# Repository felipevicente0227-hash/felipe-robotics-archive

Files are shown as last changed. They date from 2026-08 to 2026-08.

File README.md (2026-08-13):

# Felipe Robotics Archive

Robotics and embedded-systems projects, 2020–2026: international competition robots, a self-built experimental physics apparatus, and embedded control systems. Built across Taiwan, Japan, Korea, Australia, and Spain.

**About this archive.** I build physical systems and debug them until they work: sensor-driven robots, microcontroller timing systems, and electromechanical builds. My recent work centers on measurement and systematic-error analysis (Arduino photogate investigation, 2026) and embedded integration (ESP32 hovercraft, UPM Madrid, 2026). Earlier competition projects (2020–2023) document the progression from guided sensor/DC-motor builds to independently designed and coded robots.

## Engineering Progression

| Year | Project | Main engineering area | Evidence in repo |
|---|---|---|---|
| 2026 | Arduino Photogate — g measurement | Experimental design, systematic error analysis, embedded timing | Raw data (45 trials), source code, results summary, follow-up analysis, video |
| 2026 | ESP32 Hovercraft (UPM Madrid) | Embedded networking, ESC/servo integration, assembly | Code, CAD, videos, camp reference repo |
| 2023–24 | Humanoid Hand (incomplete) | Servo control, guided ML build | Photos, video |
| 2023 | Flame Guardian | Camera-based detection, IoT alerting | Detection model, alert code, demo video (YouTube) |
| 2023 | URC Australia — Mechanical Crank (1st place) | Mechanical design, threshold tuning | Design files, photos |
| 2021 | Korea RoboSTEAM — Patient Transfer (1st place) | Line-tracing algorithms, route strategy | Design files, videos, photos |
| 2020 | Japan — Light Adventurer (1st place) | Sensor zoning concept, DC motor control | Photos, video |

---

##  Flagship: [Arduino Photogate — Measuring g and Diagnosing Systematic Timing Error (2026)](photogate-free-fall/)

**Fully solo project** (IB Physics Internal Assessment): designed, built, coded, and analyzed over ~3 months of near-daily lab sessions.

A servo-release + LDR photogate free-fall rig, timed by an Arduino at microsecond resolution. Rather than a single measurement, the investigation used release height (20–100 cm, 9 heights × 5 trials) as a **diagnostic variable** to expose a systematic timing error.

**Key results:**
- Naive model (x = ½gt²): g = 8.46 m/s² — 13.8% below accepted value despite r² = 0.999
- Corrected model (t = √(2x/g) + Δt, from inspecting my own control code): **g = 9.14 ± 0.16 m/s², r² = 0.9995** (6.8% difference)
- The systematic delay was traced to a specific design decision: one button press both starts the µs timer and commands the servo release, so every trial includes the servo's rotation time
- Delay quantified two independent ways: **28 ms** (regression intercept) vs **40 ± 3.6 ms** (comparison against SUVAT-predicted times) — consistent order of magnitude from different assumptions

**What I would change:** log the servo's actual release moment via a limit switch to separate mechanical delay from LDR detection lag; replace the shared start signal with a break-beam at the release point, removing the offset at its source.

 Raw data, source code, results summary, and follow-up analysis in the [`photogate-free-fall`](photogate-free-fall/) folder. (Full report to be added after IB submission.)

---

##  [ESP32 Hovercraft — UPM Madrid Summer Camp (2026)](esp32-hovercraft-upm/)

Phone-controlled hovercraft: the ESP32 broadcasts its own Wi-Fi access point and serves a control page — thrust slider drives a brushless motor through an ESC (0–180 mapped to 1000–2000 µs pulses); steering drives a rudder servo (software-limited 45°–135°).

**My role & attribution:** Built at ETSII UPM's summer camp under instructor guidance ([camp reference repo](https://github.com/JaimeBravoAlgaba/campamento_verano_ETSII_2026)). The Wi-Fi/web framework was instructor-provided as a starter template; I completed the ESC and servo integration (pin config, pulse-width setup, control loop), and led the physical design, assembly, ESC calibration, and flight tuning within my team. Our team's own CAD variants remained on camp laptops; the archived CAD files are the camp reference designs.

---

##  [Flame Guardian (2023)](2023-flame%20guardian/)

Wildfire detection and alert system: camera-based fire detection triggering automatic email alerts with location data, designed for remote assessment and response via a web interface.

**My role:** Team of four. I led research, wrote the code, built and assembled the hardware, and integrated and tested the fire-detection model. Kristy built the demonstration diorama; a third teammate wrote the research report.

**What survives in this repo vs. the original system:** the light-sensor email-alert module (`FireDefenderMailSending.py`), the detection model (`fire_detection.xml`), and a supporting script. The integrated competition system (camera pipeline + GPS tagging + web control) is documented in the [demo video](https://www.youtube.com/watch?v=Y2XW8qYtMfY) but its full code is not archived.

**Known limitations I'd fix today:** the sensor module detects brightness *change* (1 Hz sampling), not fire directly; SMTP sending blocks execution; no Wi-Fi retry logic; detection accuracy was never formally measured.

---

##  Competition Robots (2020–2023)

### [Korea RoboSTEAM 2021 — Autonomous Patient Transfer Robot (1st place)](2021%20Korea%20Champion%20-%20Autonomous%20Patient%20Transfer%20Robot/)
Line-following robot that locates colored blocks (representing patients) and delivers each to its matching zone.
**My role:** Largely solo — pandemic restrictions meant near-daily individual lab sessions. I built the robot and wrote the tracing code, including escape functions for recovery and route strategy optimized for time-based scoring. The hardest part was tuning: the robot doesn't learn, so behavior was refined through repeated simulated runs and threshold iteration.

### [URC Australia, September 2023 — Mechanical Crank System (1st place)](2023%20Australia%20Champion%20-%20Mechanical%20Crank%20System/)
Rebuild campaign after losing at Osaka 2023 earlier that summer.
**My role:** I designed and built the new robot, wrote roughly half the code, and did all threshold tuning and testing; my teammate wrote the remaining functions.

### [Japan 2020 — Light Adventurer (1st place)](2020%20Japan%20Champion%20-%20Automatic%20Plant%20Watering%20Robot/)
A robot that moves a plant toward optimal light, then waters it automatically.
**My role:** I proposed the concept and the core sensing idea — splitting a servo's 180° sweep into three 60° zones and comparing light readings to pick a direction. My teacher taught me the implementation, building the code with me line-by-line; I did most of the physical build. Included here as the starting point of the progression, not as evidence of current ability.

---

##  [Humanoid Hand (2023–2024, incomplete)](humanoid-hand/)

Guided self-taught build of a sensor-mimicking humanoid hand from an online tutorial. Left incomplete when I moved to Spain — archived honestly as such.

## License
MIT — see [LICENSE](LICENSE).

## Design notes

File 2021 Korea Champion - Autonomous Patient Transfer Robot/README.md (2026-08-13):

# 2021 Korea Champion — Autonomous Patient Transfer Robot

Line-tracing autonomous robot that locates colored blocks (representing patients) and delivers each to its matching colored zone on a marked course. Built for the Korea RoboSTEAM competition, 2021.

## Files

- `korea - automatic Patient Transfer Robot/` — six block-editor programs (`.bpd`). These are binary files from a block-based programming environment and cannot be read as text; the specific editor they belong can be downlanded from 'https://www.artec-kk.co.jp/studuino/en/studuino.php'
  
  - `Felipe_Korea.bpd`, `Korea RoboSTEAM.bpd` — main programs
  - `FCB_UPside 0207.bpd` / `FCB_UPside 0220a.bpd`, `FCB_down0207.bpd` / `FCB_down0220A.bpd` — upper and lower mechanism programs, in dated revisions (7 Feb and 20 Feb)
- `korea championship robot map line tracing.mp4` — line tracing over the course map
- `korea championship robot trial 2.mp4` — competition trial run
- 8 build photographs (January 2021)

## Tested conditions & limitations

**Hardware disassembled — the behaviour described here is documented from the competition videos and build photographs in this folder, not from a live re-test.** The programs are stored in a binary block-editor format, and can be opened through the studuino bit prodram

The controller platform and sensor kit, the line colour and surface, and the number of line sensors were not saved, and cannot be recovered from the binary program files. Known failure modes were not written down at the time. Course length, run times, success rate and payload mass were not recorded either, and the hardware no longer exists to re-measure them.

The two dated revisions of each mechanism program (0207 → 0220) show the logic was retuned between those dates; what specifically changed is not recorded.

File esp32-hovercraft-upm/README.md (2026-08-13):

# ESP32 Hovercraft

A wi-fi controlled hovercraft built around an ESP32. The board broadcasts its own wi-fi access point and serves a control webpage — any phone that joins the network gets two sliders: one for thrust, one for steering. No app, no RC receiver, no pairing. The hovercraft is the network.

Origin & attribution: Built at ETSII UPM's summer camp under instructor guidance (camp reference repo). The Wi-Fi/web framework came as an instructor starter template; I completed the ESC and servo integration and led my team's physical design, assembly, calibration, and flight tuning. Our team's own CAD variants stayed on camp laptops — the .f3d files archived here are the camp's reference designs.

Built July 2026. Videos: hoverboard1.mp4, hoverboard2.mp4.

## How it works

The ESP32 runs in access-point mode (WiFi.softAP) and hosts a web server on port 80.

The served page has two sliders. Moving a slider sends `GET /set?device=esc&val=N` (or `device=servo`) to the board.

- Thrust: the value (0–180) drives a brushless motor through an ESC attached with 1000–2000 µs pulse widths.
- Steering: the value turns a rudder servo, constrained in software to 45°–135° so it can never slam past its physical limits.
- Failsafe: the web page sends a heartbeat ping every 300 ms. If the board hears nothing for 1 second (phone left the network, browser closed), the throttle is cut to zero automatically. Without this, a dropped connection would hold the motor at its last value forever.

## Hardware

| Part | Role |
|---|---|
| ESP32 dev board | Wi-fi access point + web server + control |
| Brushless motor + ESC | Thrust (ESC signal on GPIO 32) |
| Rudder servo | Steering (signal on GPIO 33) |
| LiPo battery | Power for ESC/motor; ESP32 powered per your setup |

## 3D-printed parts (Fusion 360)

All parts designed in Fusion 360 and 3D printed (.f3d source files in this repo):

- redirigir_aire.f3d — air-redirect duct
- soporterbrushless.f3d — brushless motor mount
- tubo.f3d — thrust tube
- timonV2.f3d — rudder (the camp's second-revision reference design)

## Setup

1. Open ESP_hovercraft.ino in the Arduino IDE with the ESP32 board package and the ESP32Servo library installed.
2. Set WIFI_SSID and WIFI_PASSWORD to whatever you want the hovercraft's network to be called.
3. Flash the board. Open the serial monitor at 115200 baud to see the access point IP (default 192.168.4.1).
4. On your phone, join the hovercraft's wi-fi network, open a browser, and go to the IP address. Slide to fly.

## Safety notes

- The throttle slider starts at 0 and the ESC arms at 0 on boot — but always treat a powered brushless motor as live. Keep fingers and loose clothing away from the fan.
- The failsafe cuts thrust on disconnect, but it does not brake the hovercraft; it will coast.
- Test with the propeller removed first when changing the code.

## Tested conditions & limitations

Everything in the **verifiable** list is read directly from `ESP_hovercraft.ino`. The second list is what has not been measured yet.

**Verifiable from the code:**

- Failsafe: the throttle is cut to zero after **1 second** without a heartbeat (`FAILSAFE_TIMEOUT_MS 1000`), with the page pinging every 300 ms — so up to three pings can be lost before it trips.
- After the failsafe fires it clears the link flag, so thrust stays at zero until the page reconnects and the slider is moved again. It does not resume on its own.
- The failsafe cuts thrust only. The rudder holds its last angle, and the hovercraft coasts rather than braking.
- Steering is constrained in software to **45°–135°**, so a malformed or out-of-range request cannot drive the rudder past its physical limits. Thrust is constrained to 0–180.
- The access point is open to anyone who joins the network and knows the IP: there is no authentication on `/set`, and traffic is plain HTTP. Anyone on the wi-fi can take control.
- **Not yet tested with two phones connected at once.** Nothing in the code arbitrates between clients, so the last request received wins and either phone's heartbeat keeps the failsafe from tripping for both.
- Control range is bounded by the ESP32's own access point, since the board makes the network rather than joining one.

**Not yet measured — the hardware remained at the UPM camp in Madrid and is no longer accessible, so these would require a rebuild:**

- Control range from the board — not yet measured
- Run time on a full battery, and the battery specification — not yet measured
- Total mass as flown — not yet measured
- Thrust value at which it lifts off the surface — not yet measured
- Failsafe behaviour in a real walk-away test, as opposed to on the bench — not yet recorded

Endurance beyond short demonstration runs was never characterised, and the two-client case noted above was never tested; with the hardware left behind at the camp, closing either gap would mean rebuilding the unit.

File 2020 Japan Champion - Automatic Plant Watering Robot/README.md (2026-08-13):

# 2020 Japan Champion — Automatic Plant Watering Robot

Championship-winning robot that tracks a light source and waters a plant automatically. Built for a robotics competition in Japan, 2020.

This folder holds build photographs (August–December 2020) and a video demo. No source code was archived for this project.

## Files

- `automatic plant watering robot video demo.mp4` — the robot running end to end
- 10 build photographs documenting the mechanism and assembly

## Tested conditions & limitations

**Hardware disassembled — the behaviour described here is documented from the competition video and build photographs in this folder, not from a live re-test.** No source code was archived either.

Verifiable from the video: a servo-mounted light sensor sweeps 0°–180°, sampling three zones — left, front, and right — stored in the block code as variables `LA`, `FA`, and `RA`. The robot compares the three readings and drives toward whichever zone is brightest, then waters the plant automatically on arrival; watering duration is adjustable in the code. Two demonstration runs are shown, one with the light source to the right and one in front, and the robot reaches the correct zone both times.

Not recoverable: the controller platform, the specific light source used in testing, the watering mechanism's hardware, and the competition category it was entered under were never saved. No quantitative figures exist either — tracking range, response time, water volume per cycle, and reservoir run time were never measured, and the hardware no longer exists to measure them now.

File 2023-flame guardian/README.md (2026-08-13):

# Flame Guardian (2023)

Fire detection system in two independent halves:

- **`fireDetect`** — runs on a laptop, watches a webcam with an OpenCV Haar cascade, draws a box around detected flame and sounds an alarm.
- **`FireDefenderMailSending.py`** — runs standalone on a Studuino:bit board, watches the on-board light sensor and sends a Gmail alert when the light level jumps.

The full competition build also included GPS location tagging, on-site image capture, and automatic extinguishing triggered through a web-based servo control interface — all demonstrated working at the time (see the servo-control webpage in the project demo). That code was never archived and no longer exists; only the two scripts above survive in this repo, and they don't communicate with each other (see Tested conditions & limitations below).

`fire_detection.xml` is the pre-trained Haar cascade used by the camera half.

## Running it

The camera half needs `opencv-python` and `pygame`, and must be run from inside this folder (it loads `fire_detection.xml` by relative path). The board half reads its wi-fi and Gmail credentials from environment variables — `WIFI_SSID`, `WIFI_PWD`, `GMAIL_ADDR`, `GMAIL_PWD`, `SEND_MAIL_ADDR` — so that no credentials live in this repo. `GMAIL_PWD` must be a Gmail App Password; with 2FA enabled Google rejects a plain account password over SMTP.

## Tested conditions & limitations

Everything in the **verifiable** list is read directly from the source in this folder. Everything after it is a real-world result that was never recorded.

**Verifiable from the code:**

- The two surviving halves never communicate. The camera half sounds an alarm but sends no email; the board half sends email but sees no camera. There is no combined mode in the code that remains in this repo.
- The board half triggers on the *change* in light level between one-second samples, not the absolute level — a jump greater than `threshold = 500` raw units. Consequences: a fire already burning when the script starts is never reported, and a fire that brightens gradually over more than a second may never produce a large enough single-sample jump.
- Sampling is 1 Hz, and `sendmail` blocks for the duration of the SMTP exchange, so detections during a send are missed.
- If wi-fi fails to connect the board shows `W` and exits — it does not retry.
- The camera half loads `audio.wav` (the alarm sound, committed alongside the script) by relative path, so it must be run from inside this folder or it will fail at startup.
- On each detection the camera half plays the alarm and sleeps 1 second, blocking the capture loop, so frames are dropped for as long as flame stays in view.
- The camera half never calls `cap.release()` or `cv2.destroyAllWindows()`; the webcam is freed only when the process exits.
- Haar cascade parameters are `scaleFactor 1.2`, `minNeighbors 5` — the false-alarm trade-off dial. It uses the default webcam (index 0).

**Not recorded anywhere in this repo:**

Detection distance, flame size and type, and the lighting conditions used in testing were not recorded at the time. Detection rate, miss rate and false-positive rate were never formally measured — the system was demonstrated rather than characterised, so there is no trial count to quote. Whether an alert email was confirmed to arrive end to end is not recorded either. The board is a Studuino:bit, identified from the `pystubit` imports; its firmware version was not noted. The GPS tagging, image capture, and servo-based extinguishing control shown in the competition demo video are not represented by any surviving code in this repo.

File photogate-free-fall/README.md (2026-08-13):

# Arduino Photogate: Measuring g and Diagnosing Systematic Timing Error

**Solo project** — designed, built, coded, and analyzed independently (IB Physics Internal Assessment, 2026). ~3 months of near-daily lab sessions.

## The question
Not just "measure g" — the investigation used release height as a **diagnostic variable**: if a fixed timing delay exists in the apparatus, it should distort short falls more than long ones. Varying height turns a nuisance error into something measurable.

## The apparatus
- Servo-controlled release arm at the top of a vertical stand
- Single LDR photogate above a catcher, read on Arduino analog pin A0 (threshold: 320/1023)
- One button press releases the sphere AND starts a microsecond timer (`micros()`)
- 200 ms ignore window after release, because the servo's own motion was found to disturb the light reading during preliminary testing
- Same metal sphere for all trials; heights 20–100 cm in 10 cm steps, 5 trials each (45 measurements)

## Key results
| Model | g (m/s²) | vs 9.81 | r² |
|---|---|---|---|
| Naive x = ½gt² | 8.46 | −13.8% | 0.9992 |
| Corrected t = √(2x/g) + Δt | **9.14 ± 0.16** | −6.8% | 0.9995 |

The corrected model came from **reading my own control code**: the timer starts at the button press, but the sphere only falls once the servo finishes rotating — so a fixed delay is added to *t*, not *t²*.

The delay was quantified two independent ways:
- **28 ms** — intercept of the t vs √x regression (no assumption about g)
- **40 ± 3.6 ms** — mean gap between measured times and SUVAT predictions (assumes g = 9.81)

Same order of magnitude from different assumptions → real, fixed offset.

## What went wrong along the way
- The servo's motion falsely triggered the LDR immediately after release → added the 200 ms ignore window
- Early trials showed derived g *rising* with height (7.16 → 8.23 m/s²) under the naive model — initially confusing, eventually the key clue that the error was a fixed additive delay

## Follow-up analysis
See [FOLLOWUP.md](FOLLOWUP.md): applying the correction flattens the per-height g values completely (σ = 0.09 m/s²), confirming the diagnosis — and reveals a residual ~6.8% systematic error the additive-delay model does not explain.

## What I would change (V2)
- Break-beam at the release point so timing starts when the fall actually starts — removing the offset at its source
- Log the servo's completion moment (limit switch / feedback pin) to separate mechanical delay from LDR lag
- More trials at 20–40 cm, where the offset is proportionally largest and most diagnostic

## Tested conditions & limitations

**Uncertainty:** timer resolution is negligible against the trial-to-trial spread. The dominant error was not random but systematic: the 28 ms to 40 ± 3.6 ms servo release delay described above.

**Verifiable from the code:**

- Timing uses `micros()` and is printed to 6 decimal places — chosen because a sub-second drop needs far finer resolution than `millis()` gives.
- `threshold = 320` is a raw `analogRead` value, calibrated against one specific lamp and room. It is not adaptive: move the rig to different ambient lighting and this must be re-tuned or the gate will either trip immediately or never trip.
- A 200 ms blanking window (`ignoreUntil`) after release ignores the photoresistor, because the servo arm sweeps through the sensor's view on its way out. Any drop that completes in under 200 ms therefore cannot be measured.
- The comparison `currentTime > ignoreUntil` is a direct unsigned comparison rather than a rollover-safe subtraction. `micros()` wraps roughly every 71 minutes of board uptime, so a run started near the wrap point can blank incorrectly. Power-cycling between sessions avoids this.
- Only one gate is present, so the device measures total time from release to the gate. It cannot measure instantaneous velocity or acceleration directly — those come from the drop height, which the sketch never knows.
- The sketch prints a serial line on every loop iteration while timing. At 115200 baud these writes block once the buffer fills, so the photoresistor sampling interval is bounded by serial throughput, not by the loop itself. This adds jitter to when the shadow is actually noticed.
- After a run auto-stops, the servo gate position and the timer state are tracked by two separate flags that are only toggled together on a button press — so the gate can end up in the opposite position from the one the next run expects. See "Known issue" below.

**Known issue (documented, not fixed):** `detecting` is cleared automatically when the ball is detected, but `at90` is not. The next button press therefore moves the servo to 50° instead of 90° while starting a new timing run, so the gate needs an extra press to resynchronise.

**Not measured:** the residual ~6.8% gap between the corrected g and 9.81 m/s² is unexplained by the additive-delay model. Separating LDR detection lag from height-measurement bias needs the V2 hardware changes above; neither was measured here.

## Files
- `final_project_code.ino` — release + timing code
- `raw_data.csv` — all 45 trial times
- `felipe 2026 physics ia free fall experiment using arduino.mp4` — video of the experiment running
- `FOLLOWUP.md` + `photogate_correction_followup.png` — post-IA correction analysis
- `generate_figure.py` — reproduces the figure from the data
- Full IA report: added after IB submission (academic integrity)

## TODO
- [ ] Apparatus photo at top
- [ ] t vs √x regression graph

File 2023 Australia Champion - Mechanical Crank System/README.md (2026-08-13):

# 2023 Australia Champion — Mechanical Crank System

Mechanical crank system built for the URC competition, Australia, 2023.

The competition took place in September 2023. The later materials in this folder — program revisions dated November 2023, December photographs, and the URC-AUS-2024 revision — are post-competition development toward the following URC season.

## Files

- `2023- australia/` — four block-editor programs (`.bpd`). These are binary files from a block-based programming environment and cannot be read as text; the specific editor they belong can be downloaded from'https://www.artec-kk.co.jp/studuino/en/studuino.php'
  
  - `URC20231113.bpd`, `URC20231126.bpd`, `URC-AUS-2024.bpd` — post-competition revisions, all dated after the September 2023 event (13 Nov 2023, 26 Nov 2023, and a later 2024 revision); none of them is the version run at the competition
  - `備品機_URC澳洲.bpd` — a separate variant; what distinguishes it from the others was not recorded
- 5 build photographs (September and December 2023)

## Tested conditions & limitations

**Hardware disassembled — the behaviour described here is documented from the build photographs in this folder, not from a live re-test.** There is no video demo for this project,the programs are stored in a binary block-editor format, and can be opened using the studuino bit program listed above 

The controller platform and actuators, the mechanical function of the crank itself, the competition task it performed and its result, and its known failure modes were not recorded, and cannot be recovered from the binary program files or the photographs. Load, torque, range of travel and cycle time were never measured; the system was built to complete a competition task rather than to a specification, and the hardware no longer exists to measure them now.

The three dated revisions (13 Nov 2023 → 26 Nov 2023 → 2024) show the design was iterated after the September 2023 competition; what specifically changed between them is not recorded.

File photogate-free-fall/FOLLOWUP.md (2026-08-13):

## Follow-up analysis: applying the timing correction

The original investigation's Improvements section proposed applying the identified timing correction directly and re-running the analysis. Done here, using the same raw data (no new hardware required).

**Method:** subtract each delay estimate from every measured average time (t_corrected = t − Δt), then recompute per-height g = 2x/t² and re-fit the naive t² vs x model.

**Results:**

| Correction applied | Regression g (m/s²) | vs 9.81 | Per-height g spread |
|---|---|---|---|
| None (original) | 8.46 | −13.8% | 7.16 → 8.23 (rises with height) |
| Δt = 28 ms (regression intercept) | 9.14 | −6.8% | 9.03 → 9.31 (flat, σ = 0.09) |
| Δt = 40.3 ms (SUVAT offset) | 9.48 | −3.4% | mean 9.86 ± 0.24 |

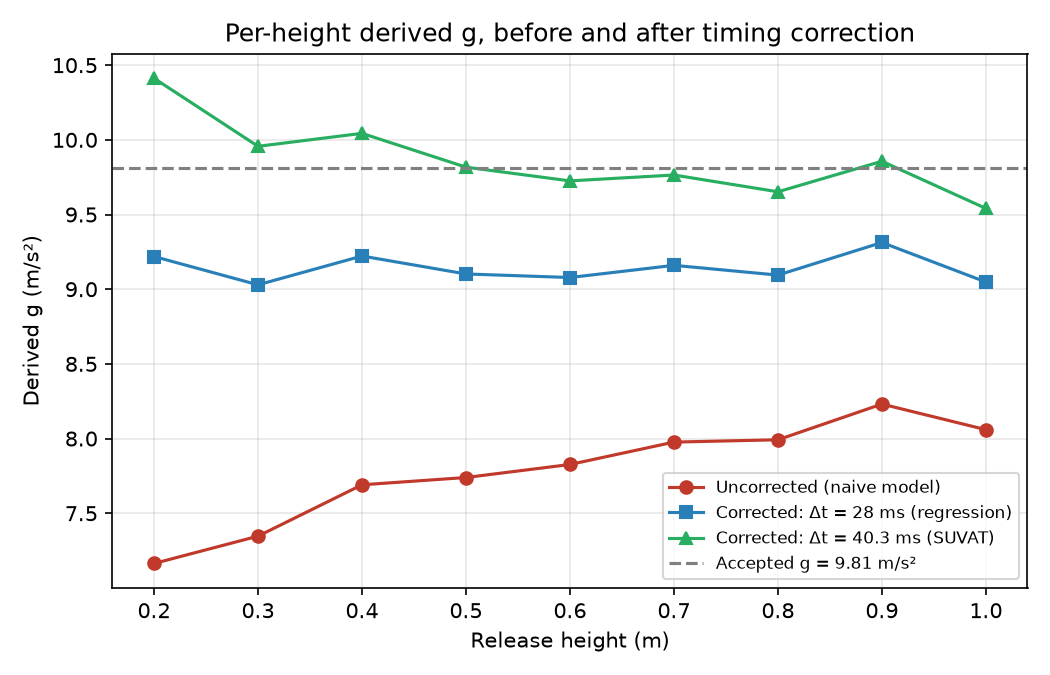
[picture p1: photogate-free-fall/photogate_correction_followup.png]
Per-height g before and after correction


**What this shows:**

1. **The diagnosis is confirmed.** Uncorrected, derived g climbs systematically with height (7.16 → 8.23) — the fingerprint of a fixed additive delay. After the 28 ms correction, that trend vanishes: g is flat across all nine heights (σ = 0.09 m/s²). The height-dependence was entirely an artifact of the timing offset, as predicted.

2. **One honest caveat:** re-fitting after subtracting the regression's own intercept necessarily returns the same g (9.14) — that step is a self-consistency check, not new information. The genuinely new result is the flattening of the per-height values.

3. **A residual systematic error remains.** Even fully corrected by the data-derived delay, g = 9.14 sits 6.8% below 9.81 — larger than the statistical uncertainty (±0.16). The additive-delay model explains the height-dependence but not the entire gap. Remaining candidates: LDR detection lag that grows with impact speed, a small systematic height measurement bias, or the sphere receiving a slight push at release. Distinguishing these requires the hardware changes proposed in Improvements (release-point break-beam, servo feedback logging).

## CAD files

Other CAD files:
esp32-hovercraft-upm/redirigir aire.f3d
esp32-hovercraft-upm/soporterbrushless.f3d
esp32-hovercraft-upm/timonV2.f3d
esp32-hovercraft-upm/tubo.f3d

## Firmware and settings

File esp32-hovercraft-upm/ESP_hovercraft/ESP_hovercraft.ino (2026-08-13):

#include <ESP32Servo.h>
#include <WiFi.h>
#include <WebServer.h>

// ESP32 Wi-Fi network name and password
#define WIFI_SSID "any user name"
#define WIFI_PASSWORD "any password"

// Brushless ESC and servo pins
#define PIN_ESC 32
#define PIN_SERV 33

// Failsafe: if no message arrives from the phone for this long,
// the throttle is cut to zero. The web page sends a heartbeat every
// 300 ms, so this only triggers on a real disconnect.
#define FAILSAFE_TIMEOUT_MS 1000

Servo esc;
Servo servo;
WebServer server(80);

// ---------- ESC ----------
// ESC value received from the web interface (0 = motor off)
int escweb = 0;

// ---------- SERVO ----------
// Servo value received from the web interface (90 = rudder centered)
int servoweb = 90;

// ---------- FAILSAFE ----------
unsigned long lastContactMs = 0; // last time we heard from the client
bool linkActive = false; // true once a client has connected

// Web page (HTML)
const char index_html[] PROGMEM = R"rawliteral(
<!DOCTYPE html>
<html>
<head>
<meta name="viewport" content="width=device-width, initial-scale=1">
<title>Brushless and Servo Control</title>
<style>
body {
font-family: Arial;
text-align: center;
margin: 0;
padding: 20px;
}
h2 { margin-bottom: 20px; }
.value { font-weight: bold; font-size: 1.3em; }

.control-block {
margin: 25px auto;
max-width: 500px;
}
.slider {
width: 90%;
height: 40px;
}
</style>
<script>
function updateESC(value) {
document.getElementById("escweb").innerText = value;
fetch("/set?device=esc&val=" + value);
}
function updateServo(value) {
document.getElementById("servoweb").innerText = value;
fetch("/set?device=servo&val=" + value);
}
// Heartbeat: tell the hovercraft we are still connected.
// If these stop arriving (phone left the network, browser
// closed), the failsafe cuts the motor within one second.
setInterval(function () {
fetch("/ping").catch(function () {});
}, 300);
</script>
</head>
<body>
<h2>Brushless and Servo Control</h2>

<div class="control-block">
<h3>Brushless Motor</h3>
<input type="range" min="0" max="180" value="0" class="slider"
oninput="updateESC(this.value)">
<div>Value: <span id="escweb" class="value">0</span></div>
</div>

<div class="control-block">
<h3>Servo</h3>
<input type="range" min="45" max="135" value="90" class="slider"
oninput="updateServo(this.value)">
<div>Value: <span id="servoweb" class="value">90</span></div>
</div>

</body>
</html>
)rawliteral";

void markContact() {
lastContactMs = millis();
linkActive = true;
}

void handleRoot() {
markContact();
server.send(200, "text/html", index_html);
}

void handlePing() {
// Heartbeat from the web page; refreshes the failsafe timer.
markContact();
server.send(200, "text/plain", "OK");
}

void handleNotFound() {
server.send(404, "text/plain", "Not found");
}

void handleSet() {
String device = server.arg("device"); // "servo" or "esc"
String valStr = server.arg("val");

markContact();

if (valStr.length() == 0) {
server.send(400, "text/plain", "Missing 'val' parameter");
return;
}

int newValue = valStr.toInt();

if (device == "esc") {
// Store the ESC value
escweb = constrain(newValue, 0, 180);
server.send(200, "text/plain", "OK");
}
else if (device == "servo") {
// Store the servo value
servoweb = constrain(newValue, 45, 135);
server.send(200, "text/plain", "OK");
}
else {
server.send(400, "text/plain", "Invalid device. Use 'esc' or 'servo'");
}
}

void setup() {
Serial.begin(115200);

// Attach ESC (minimum and maximum pulse widths in microseconds)
esc.attach(PIN_ESC, 1000, 2000);
servo.attach(PIN_SERV);

// Initialize ESC and servo positions (motor off, rudder centered)
esc.write(escweb);
servo.write(servoweb);

// -------- Wi-Fi Access Point Setup --------
WiFi.mode(WIFI_AP);
WiFi.softAP(WIFI_SSID, WIFI_PASSWORD); // Create its own Wi-Fi network

IPAddress apIP = WiFi.softAPIP(); // Assign the access point IP address
Serial.print("Access point IP: ");
Serial.println(apIP);

// Serve the web page when a client requests the root URL
server.on("/", handleRoot);

// Receive slider values and store them
server.on("/set", handleSet);

// Heartbeat endpoint for the failsafe
server.on("/ping", handlePing);

server.onNotFound(handleNotFound);

server.begin();
Serial.println("Web server started");
}

void loop() {
// Check for incoming HTTP client requests
server.handleClient();

// -------- Failsafe --------
// If the phone disconnects mid-flight, the last throttle value
// would otherwise be held forever. Cut the motor to zero if we
// haven't heard from the client within the timeout.
if (linkActive && (millis() - lastContactMs > FAILSAFE_TIMEOUT_MS)) {
escweb = 0;
linkActive = false;
Serial.println("Failsafe: connection lost, throttle cut to 0");
}

// Send the latest values to the ESC and servo
esc.write(escweb);
servo.write(servoweb);
}

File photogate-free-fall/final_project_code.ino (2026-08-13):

// Photogate timer for a free-fall experiment (IB Physics IA).
//
// A servo holds a ball at the top of the drop. Pressing the button releases the
// ball and starts a timer in the same instant, so the timer measures the true
// fall time rather than a human's reaction to seeing the ball move. The ball
// falling past a photoresistor at the bottom casts a shadow, which stops the
// timer. Elapsed time is printed over serial for the g calculation.
//
// Timing is done in micros() rather than millis() because a ~0.5 s drop needs
// resolution far finer than 1 ms to keep the uncertainty in g acceptable.

#include <Servo.h>

const int buttonPin = 13;
const int photoresistorPin = A0; // analog: the gate reads a light *level*, not a digital edge

Servo myServo;

bool detecting = false;   // timer currently running
bool at90 = false;        // servo gate position: true = 90 (open), false = 50 (holding)
int lastButtonState = HIGH; // HIGH = released, because the button uses INPUT_PULLUP

// Light level below which the ball is considered to have passed the gate.
// Set from the raw analogRead values observed on the bench: well under the
// ambient reading, well above the reading with the ball blocking the sensor,
// so ordinary room-light flicker cannot trip it. Re-tune this if the lamp or
// the room changes.
int threshold = 320;

unsigned long startTime = 0;   // micros() at release
unsigned long ignoreUntil = 0; // blanking deadline; see below

void setup() {
  Serial.begin(115200); // faster serial speed

  // INPUT_PULLUP uses the internal resistor, so the button wires straight to
  // ground with no external pull-up on the breadboard. This is why the logic
  // below is inverted (pressed = LOW).
  pinMode(buttonPin, INPUT_PULLUP);

  myServo.attach(10);
  myServo.write(0);
}

void loop() {
  int buttonState = digitalRead(buttonPin);

  // Button press
  // Edge-triggered on HIGH->LOW: fires once on the press instead of
  // continuously for as long as the button is held down.
  if (lastButtonState == HIGH && buttonState == LOW) {

    detecting = !detecting;
    at90 = !at90;

    // Move servo
    // Releasing the ball and starting the clock happen in the same button
    // press, which is the whole point - it removes human reaction time from
    // the measurement.
    myServo.write(at90 ? 90 : 50);

    if (detecting) {
      startTime = micros();
      // Blanking window: ignore the photoresistor for the first 200 ms after
      // release. The servo arm sweeps across the sensor's view on its way out
      // and would otherwise cast a shadow that stops the timer immediately.
      // 200 ms comfortably outlasts the servo travel while still being far
      // shorter than the drop itself.
      ignoreUntil = micros() + 200000UL;

      Serial.println("Timer started");
    }
    else {
      Serial.println("Timer stopped");
    }
  }

  lastButtonState = buttonState;

  if (detecting) {

    unsigned long currentTime = micros();
    unsigned long elapsed = currentTime - startTime;

    int light = analogRead(photoresistorPin);

    Serial.print("Time: ");

    // convert microseconds to seconds
    // 6 decimal places: printing fewer would throw away the microsecond
    // resolution the whole timing approach exists to get.
    Serial.print(elapsed / 1000000.0, 6);

    Serial.print(" s   Light: ");
    Serial.println(light);

    // stop after ignore period
    // Both conditions matter: the blanking window must have expired *and* the
    // light must have dropped, otherwise the servo's own shadow ends the run.
    if (currentTime > ignoreUntil && light < threshold) {

      detecting = false;

      Serial.println("Stopped: light below threshold");

      // The number the experiment actually wants. Everything printed above is
      // a live trace for confirming the gate saw a clean single shadow.
      Serial.print("Final Time: ");
      Serial.print(elapsed / 1000000.0, 6);
      Serial.println(" s");
    }
  }

}
